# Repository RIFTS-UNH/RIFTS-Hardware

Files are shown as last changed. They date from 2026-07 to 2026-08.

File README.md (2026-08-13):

# RIFTS Hardware Documentation

Mechanical design archive and documentation for the **Radio Interferometer For Thunderstorm Studies (RIFTS)** project at the University of New Hampshire.

📖 **Live documentation site:** [rifts-unh.github.io/RIFTS-Hardware](https://rifts-unh.github.io/RIFTS-Hardware/)

This repository holds the source for that site. It covers mechanical enclosure design, additively manufactured components, CAD reference models, manufacturing files, environmental validation testing, and engineering lessons learned across the RIFTS hardware platforms — the RFSoC 4x2 portable field enclosure, the ZCU216 rack-mount enclosure, the OmniLOG antenna mount system, and supporting accessories.

For the full write-ups, navigation, and images, visit the site linked above rather than browsing this repo directly.

---

## Repository Contents

```
RIFTS-Hardware/
├── .github/
│   └── workflows/
│       └── deploy.yml   # builds and deploys the site to GitHub Pages on push to main
├── docs/                # mkdocs source (pages, images, assets for the documentation site)
├── mkdocs.yml            # site configuration
└── README.md
```

Large CAD assemblies and manufacturing archives are tracked with Git LFS. Clone with `git lfs install` set up beforehand, or run `git lfs pull` after cloning, to fetch them.

---

## Building the Site Locally

```bash
pip install mkdocs-material mkdocs-glightbox
mkdocs serve
```

Then open `http://127.0.0.1:8000` to preview locally. Pushes to `main` trigger `.github/workflows/deploy.yml`, which builds the site with `mkdocs build` and deploys it to GitHub Pages automatically.

---

## Acknowledgements

This hardware was developed as part of the **Radio Interferometer For Thunderstorm Studies (RIFTS)** project at the University of New Hampshire.

Additional hardware contributions and reference designs:

- **Frank Lind, MIT Haystack Observatory** — RF Interface Board reference design
- **AMD Xilinx** — ZCU216 RFSoC Development Platform, RFSoC 4x2 Development Platform
- **SparkFun Electronics** — ZED-F9T GNSS Timing Breakout, ESP32 WROOM Thing Plus

---

## Maintainer

Mechanical design and documentation: **Joshua D'Addario**

---

## FLASH-MEP

FLASH-MEP parts sheet  https://docs.google.com/spreadsheets/d/1aVYJW8B82nQ8EhuhUXIeyBJPT4pah5DBl2TXt3p7wDM/edit?gid=0#gid=0

Wed Aug 12 18:59:08 EDT 2026

## Revision History

| Revision | Date | Description |
| --- | --- | --- |
| Rev A | July 2026 | Initial RIFTS hardware documentation archive. |
| Rev B | Aug 2026  | Repository cleaned up to contain only mkdocs source and its GitHub Actions deploy workflow; README rewritten to point to the live site rather than duplicate it. |

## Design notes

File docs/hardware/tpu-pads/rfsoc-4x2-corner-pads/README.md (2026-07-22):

# RFSoC 4x2 TPU Corner Pad System

Installed Corner Pads

---

# Project Summary

| | |
|---|---|
| **Project** | RFSoC 4x2 TPU Corner Pad System |
| **Purpose** | Protective corner assemblies for portable enclosure handling and transportation |
| **Associated Platform** | RFSoC 4x2 Portable Field Enclosure |
| **Manufacturing Method** | FDM Additive Manufacturing |
| **Primary Material** | TPU |
| **Rigid Insert Material** | PLA Prototype / PETG Recommended |
| **Threaded Hardware** | M3 Brass Heat-Set Inserts |
| **Printer** | Bambu Lab A1 |
| **Status** | Complete |

---

# Overview

The RFSoC 4x2 TPU Corner Pad System was developed specifically for the portable RIFTS RFSoC 4x2 enclosure to improve durability during transportation, handling, and field deployment.

Unlike the laboratory-oriented ZCU216 enclosure, the RFSoC 4x2 platform was designed for repeated transportation and operation outside of a controlled laboratory environment.

The corner pad assemblies provide mechanical protection for the aluminum enclosure while improving stability when placed on uneven or irregular surfaces.

---

# Design Purpose

The corner pad assemblies were developed to:

- Protect enclosure corners during transportation and handling.
- Reduce impact forces transferred to the aluminum enclosure.
- Improve stability on uneven surfaces.
- Provide a high-friction interface between the enclosure and supporting surfaces.
- Improve long-term durability of the portable hardware platform.

---

# Assembly Design

Each enclosure corner uses a **unique corner pad assembly** designed to accommodate the specific geometry of that enclosure corner.

The complete system consists of four separate corner assemblies.

Each assembly contains:

- Four TPU body sections.
- Ten custom rigid insert components.
- Ten M3 brass heat-set threaded inserts.
- Mechanical fasteners for final assembly.

The rigid insert components are bonded into dedicated pockets within the TPU sections.

Because TPU is flexible and does not provide an ideal material for directly installing heat-set inserts, rigid printed inserts were incorporated to provide a more reliable threaded interface.

The heat-set inserts are installed into the rigid insert components, allowing the TPU sections to be mechanically fastened together into a complete three-dimensional corner pad assembly.

This modular construction allows damaged sections to be replaced individually rather than requiring replacement of an entire corner assembly.

---

# Material Selection

## TPU Corner Components

The protective corner sections were manufactured using Thermoplastic Polyurethane (TPU).

TPU was selected due to:

- High impact resistance.
- Flexibility under loading.
- Abrasion resistance.
- High surface friction.
- Ability to absorb mechanical shocks.

Compared with rigid thermoplastics, TPU provides improved energy absorption and reduces the likelihood of transmitting impact forces directly into the aluminum enclosure.

---

## Rigid Insert Components

The rigid insert components were originally manufactured using PLA to support rapid prototyping and design iteration.

For future manufacturing, **PETG is recommended** because it provides:

- Improved toughness.
- Increased impact resistance.
- Better elevated-temperature performance.
- Reduced brittleness during repeated assembly.

---

# Heat-Set Insert Installation

The M3 brass heat-set inserts are installed into the rigid printed insert components.

Recommended installation procedure:

1. Heat a soldering iron to approximately **230°C**.
2. Use a heat-set insert press attachment designed for soldering irons to maintain alignment during installation.
3. Insert the brass threaded insert into the prepared hole.
4. Ensure the **serrated face of the heat-set insert faces outward toward the opening of the hole**.
   - The serrated surface should face upward/outward.
   - It should not point deeper into the printed insert.
5. Apply heat and gently press the insert into position until fully seated.

A suitable heat-set insert press attachment can be purchased commercially.

Example:

https://www.amazon.com/Vertical-Machine-Heat-Insertion-Threaded-Components/dp/B0DHKPHKJZ

---

# Design Features

The completed corner pad assemblies provide:

- Full enclosure corner protection.
- Replaceable modular construction.
- Flexible impact absorption.
- Increased friction against supporting surfaces.
- Improved stability during transportation.
- Lightweight construction.

The modular design allows individual TPU sections or rigid inserts to be replaced without recreating the entire assembly.

---

# Gallery

## CAD Model

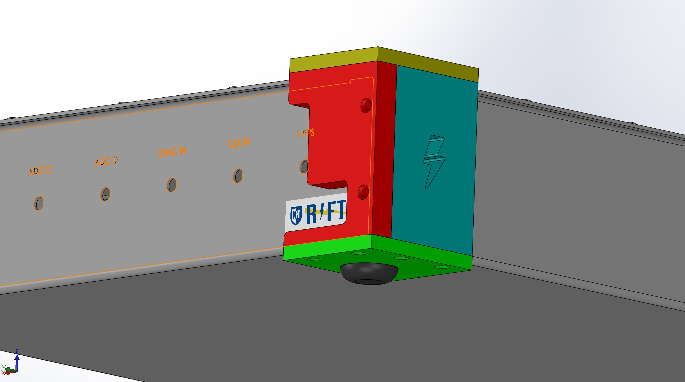
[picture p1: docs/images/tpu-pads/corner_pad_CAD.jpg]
Corner Pad CAD


Representative CAD model of a corner pad assembly.

---

## Installed Assembly

Installed Corner Pad

Completed corner pad assemblies installed on the RFSoC 4x2 enclosure.

---

# Manufacturing

The corner pad assemblies were manufactured using fused deposition modeling (FDM) additive manufacturing.

## Manufacturing Details

| Component | Material | Manufacturing Method |
|---|---|---|
| TPU corner sections | TPU | FDM 3D Printing |
| Rigid insert components | PLA Prototype / PETG Recommended | FDM 3D Printing |
| Threaded inserts | Brass M3 Heat-Set Inserts | Commercial Hardware |

Printer:

- Bambu Lab A1

Future manufacturing packages may include Bambu Studio (`.3mf`) files containing validated print profiles.

---

# File Organization

```text
rfsoc-4x2-corner-pads/

├── Common_Components/
│   └── Corner_Pad_Insert/
│       ├── CAD/
│       └── STL/
│
├── Corner_Pad_1/
│   ├── Assembly/
│   ├── CAD/
│   └── STL/
│
├── Corner_Pad_2/
│
├── Corner_Pad_3/
│
└── Corner_Pad_4/
```

---

# Downloads

The repository includes:

## Common Components

- Native SolidWorks CAD for rigid insert components.
- STL files for additive manufacturing.

## Corner Pad Assemblies

Each corner assembly includes:

- SolidWorks assembly files (`.SLDASM`).
- Native SolidWorks part files (`.SLDPRT`).
- STL files for additive manufacturing.

Future revisions may include:

- STEP exports.
- Exploded assembly drawings.
- Bambu Studio (`.3mf`) print files.

---

# Associated Hardware Platform

The corner pad system was developed exclusively for the RFSoC 4x2 portable enclosure.

These assemblies are not used on the ZCU216 enclosure platform.

---

# Revision History

| Revision | Date | Description |
|---|---|---|
| Rev A | July 2026 | Initial corner pad assembly documentation and archive release. |

---

# Credits

Mechanical design and documentation:

**Joshua D'Addario**

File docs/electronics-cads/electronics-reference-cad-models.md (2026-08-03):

# Electronics Reference CAD Models

## Overview

This section catalogs the mechanical CAD reference models of electronic hardware collected over the course of RIFTS project developments, used to support enclosure design, mechanical integration studies, connector placement verification, and internal packaging development.

These are **mechanical reference models only** — dimensional and geometric representations used for CAD integration work, not schematics, PCB layout, or electrical design files.

The collection includes both manufacturer-provided models and models created or derived in-house from available references, sourced from a mix of manufacturers, collaborators, and third parties.

---

## Models in This Collection

| Model | Designer / Manufacturer | Source | Simplified Version Available |
|---|---|---|:---:|
| AMD Xilinx RFSoC 4x2 Development Board | AMD | Provided directly by an AMD representative | Yes |
| AMD Xilinx ZCU216 Development Board | AMD | Purchased from a third-party CAD vendor | No |
| RF Interface Board | Frank Lind, MIT Haystack Observatory | Provided by the designer for RIFTS integration | Yes |
| SparkFun ZED-F9T GNSS Timing Breakout (Qwiic) | SparkFun Electronics | Converted from SparkFun's published Eagle files | No |
| SparkFun ESP32 WROOM Thing Plus (Micro B) | SparkFun Electronics | Converted from SparkFun's published Eagle files | No |
| Ethernet Cat5e Bulkhead Connector | Third-party | Sourced from GrabCAD | No |
| Type A Duct Fan | Sanyo Denki | Sourced from DigiKey | No |
| Type B Duct Fan | Sanyo Denki | Sourced from DigiKey | No |

!!! note "SparkFun models are board outline only"
    Both SparkFun models (ZED-F9T and ESP32 Thing Plus) represent the bare PCB geometry only — mounting holes, board outline, and connector locations — without populated components. Full component-level geometry could not be reliably converted from SparkFun's Eagle files. This was sufficient for the mechanical integration work these models were created for, but worth knowing in advance if you're requesting one for a different purpose.

---

## Requesting Files

!!! warning "Files not publicly distributed"
    These models are not available for direct download from this site. Ownership and redistribution rights vary by source — some are manufacturer-owned geometry, some are provided by outside collaborators, and some come from third-party repositories with unclear redistribution terms.

    If you need one of these files, **contact a RIFTS executive** to request it. They can determine whether a given model is appropriate to share on a case-by-case basis.

    <!-- TODO: add RIFTS executive contact name/email here -->

---

## How These Models Are Used

Reference models in this collection support:

- Enclosure and chassis design
- Mechanical integration studies across hardware platforms
- Connector and cable pathway placement
- Internal packaging and clearance verification
- General hardware visualization for documentation

Where appropriate, simplified versions of these models are used in place of full manufacturer geometry — removing unnecessary cosmetic and internal detail while preserving mechanically relevant features such as board envelope dimensions, mounting hole locations, and connector placement. This improves CAD performance during enclosure design work.

Simplified versions currently exist for the **AMD Xilinx RFSoC 4x2 Development Board** and the **RF Interface Board**. These simplified models retain only mechanically significant geometry — external dimensions, connector locations, and mounting interfaces — and are available as an alternative to the full-detail manufacturer models on request.

---

## Revision History

| Revision | Date | Description |
|---|---|---|
| Rev A | July 2026 | Initial electronics reference model catalog. |

---

## Credits

CAD collection and documentation: **Joshua D'Addario**

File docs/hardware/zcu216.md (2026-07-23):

# ZCU216 RF Shielded Enclosure

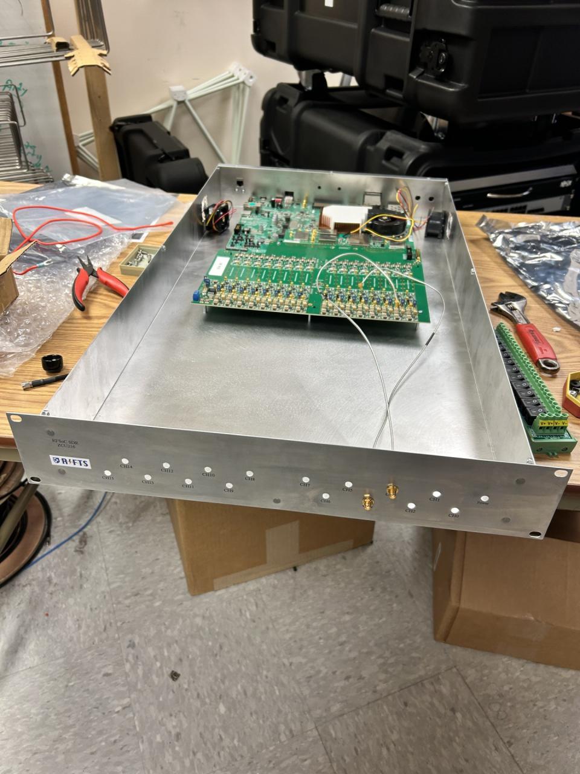
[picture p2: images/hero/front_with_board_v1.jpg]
ZCU216 Enclosure


## Project Summary

| | |
|---|---|
| **Project** | ZCU216 RF Shielded Enclosure |
| **Purpose** | EMI-shielded enclosure for laboratory integration of the AMD Xilinx ZCU216 RFSoC platform |
| **Platform** | AMD Xilinx ZCU216 RFSoC Development Board |
| **Application** | Radio Interferometer for Thunderstorm Studies (RIFTS) |
| **Manufacturer** | Protocase |
| **Material** | 5052 Aluminum |
| **Revision A Thickness** | 0.040 in (1.02 mm) |
| **Revision B Thickness** | 0.051 in (1.30 mm) |
| **Cooling** | Dual forced-air cooling (side-mounted intake and exhaust fans) |
| **Shielding Strategy** | Conductive aluminum enclosure with seam-welded construction, dense fastener spacing, and controlled aperture geometry |
| **Status** | Revision B Complete |
| **Related Hardware** | MIT Haystack RF Interface Board, RFSoC 4x2 Enclosure, Air Ducts |

---

## Overview

The ZCU216 RF Shielded Enclosure was the first major mechanical hardware platform developed for the University of New Hampshire's Radio Interferometer for Thunderstorm Studies (RIFTS) project.

The enclosure was designed to integrate the AMD Xilinx ZCU216 RFSoC development platform with the MIT Haystack RF Interface Board while providing mechanical protection, electromagnetic shielding, active cooling, and convenient laboratory operation within a standard 2U rack-mounted form factor.

Beyond simply housing electronics, this project established many of the mechanical design philosophies that would later influence the portable RFSoC 4x2 enclosure, including approaches to EMI mitigation, airflow management, manufacturability, and enclosure construction.

## Design Requirements

The enclosure was developed to satisfy several engineering requirements:

- Provide secure mechanical integration of the AMD Xilinx ZCU216 RFSoC platform.
- Integrate the MIT Haystack RF Interface Board within the same enclosure.
- Minimize electromagnetic emissions and susceptibility through conductive enclosure design.
- Support forced-air cooling for continuous laboratory operation.
- Package the system within a standard 2U rack-mounted form factor.
- Maintain accessibility to all required external interfaces.
- Allow repeatable assembly and servicing.

---

## Design Rationale

The enclosure was conceived as an RF engineering enclosure rather than simply a protective chassis. Several design decisions were driven specifically by electromagnetic compatibility (EMC) considerations.

### Conductive Construction

5052 aluminum was selected because it offers an excellent balance between electrical conductivity, manufacturability, corrosion resistance, structural performance, and cost.

Unlike painted steel enclosures or polymer housings, the conductive aluminum body contributes directly to electromagnetic shielding performance.

### Mechanical Rigidity

Revision A demonstrated that although 0.040-inch aluminum was adequate structurally, increasing wall thickness would substantially improve enclosure rigidity. Revision B therefore increased the enclosure thickness to 0.051-inch aluminum.

The resulting enclosure is noticeably more rigid during transportation, assembly, and servicing while also providing modest improvements in low-frequency shielding performance.

### Seam Welding

One of the most significant improvements introduced in Revision B was seam welding. Continuous welded seams eliminate narrow gaps that can behave as unintended slot antennas.

Reducing these discontinuities improves overall shielding effectiveness while simultaneously increasing enclosure rigidity. This change became one of the most influential design improvements carried forward into later RIFTS hardware.

### Cooling Strategy

Thermal management is provided using two internally mounted fans. Both the intake and exhaust fans are mounted directly to the enclosure side panels.

This arrangement produces a straightforward airflow path through the enclosure while simplifying manufacturing and maintenance. Unlike the later RFSoC 4x2 enclosure, neither fan is mounted directly to the RFSoC heatsink.

### EMI Shielding Philosophy

Rather than relying upon expensive conductive elastomer gaskets throughout the enclosure, the shielding strategy emphasized:

- Conductive aluminum construction
- Seam welding
- Controlled aperture geometry
- Dense fastener spacing around removable panels

This approach provided a practical balance between shielding performance and manufacturing cost.

---

## Key Engineering Improvements

| Revision | Major Improvements |
|---|---|
| **Rev A (August 2025)** | Initial enclosure design establishing overall architecture, board integration, cooling layout, and shielding strategy. |
| **Rev B (December 2025)** | Increased wall thickness, seam-welded construction, improved vent placement, relocated panel labels, and increased overall structural rigidity. |

---

## Mechanical Design

The enclosure consists of a welded aluminum chassis with a removable cover.

Internal features include mounting provisions for:

- AMD Xilinx ZCU216 RFSoC Development Board
- MIT Haystack RF Interface Board
- Forced-air cooling hardware
- Standardized Protocase PEM hardware

The removable cover provides convenient service access while maintaining shielding continuity through closely spaced fasteners.

---

## Gallery

### Complete Enclosure

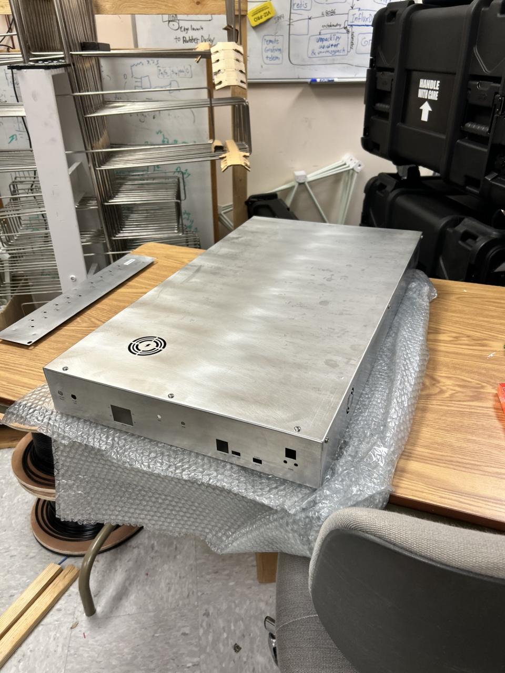
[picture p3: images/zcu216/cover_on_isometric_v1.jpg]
ZCU216 Isometric View

*Overall isometric view of the completed enclosure.*

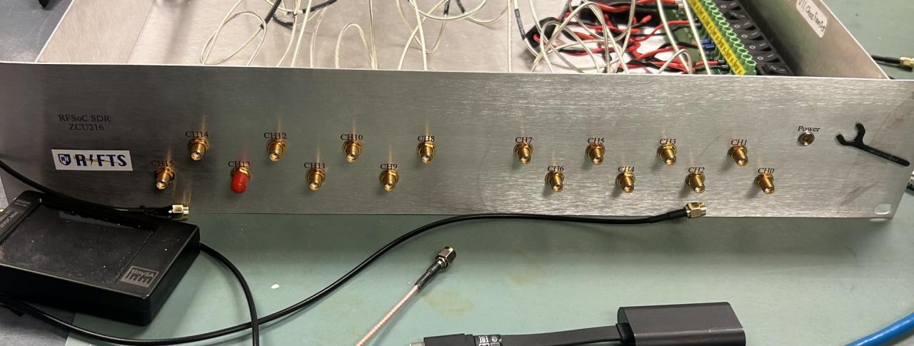
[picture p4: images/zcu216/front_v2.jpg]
Front View

*Front panel showing external interfaces and rack mounting features.*

### Internal Assembly

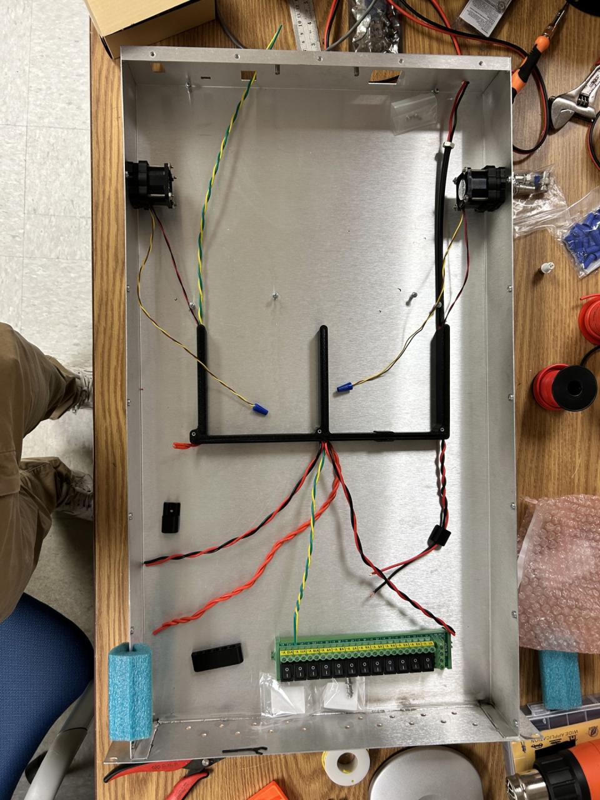
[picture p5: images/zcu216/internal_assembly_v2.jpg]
Internal Assembly

*Internal view showing the AMD Xilinx ZCU216 RFSoC platform, MIT Haystack RF Interface Board, cooling hardware, and enclosure layout.*

### Rear Panel

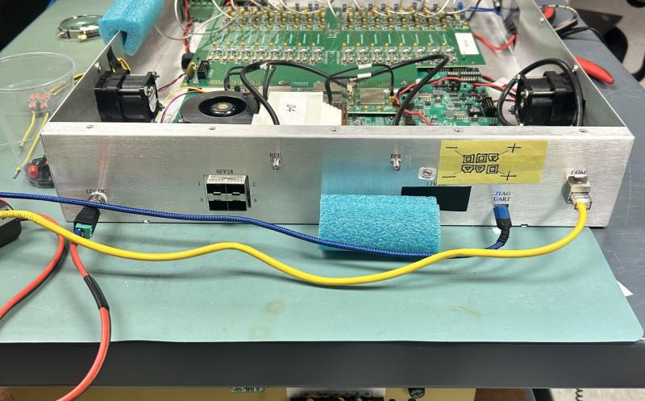
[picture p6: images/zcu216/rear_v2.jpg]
Rear Panel

*Rear panel detailing RF and electrical interfaces.*

---

## Directory Contents

The repository preserves both the final enclosure design and the reference models used throughout development.

### Board CAD

Reference CAD models used during enclosure development.

**AMD Xilinx ZCU216 Development Board**
`AMD_Xilinx_ZCU216_Board.SLDPRT` — manufacturer-supplied CAD model of the AMD Xilinx ZCU216 RFSoC development platform.

**MIT Haystack RF Interface Board**
`MIT_Haystack_RF_Interface_Board.SLDPRT` — high-fidelity CAD model of the RF Interface Board developed by Frank Lind at MIT Haystack Observatory.

**Simplified RF Interface Board**
`MIT_Haystack_RF_Interface_Board_Simplified.SLDPRT` — simplified reference model developed specifically for enclosure design. Only mechanically significant geometry was retained in order to improve SolidWorks performance while preserving:

- External dimensions
- Connector locations
- Mounting interfaces
- Overall board envelope

The simplified model is recommended for future enclosure development unless detailed internal geometry is required.

### Enclosure CAD

The completed enclosure model is provided in neutral CAD format.

Available formats:

- STEP

### Manufacturing Files

Manufacturing documentation includes the original fabrication package used for production by Protocase.

Available formats:

- Protocase PDA

These files preserve the exact enclosure geometry submitted for manufacturing and may be used for future revisions or reproduction.

---

## Manufacturing Notes

The enclosure was fabricated by Protocase using CNC sheet metal manufacturing techniques.

Standardized PEM hardware supplied by Protocase was incorporated throughout the design for board mounting and cover attachment. Although the enclosure was custom designed, the use of standardized manufacturing hardware simplified fabrication and ensured compatibility with Protocase manufacturing processes.

## CAD Model Notes

Several reference models are intentionally provided in both original and simplified forms.

The simplified models remove unnecessary cosmetic and internal features while preserving all mechanically significant geometry. Using simplified reference models substantially improves CAD performance, rebuild times, and assembly responsiveness without affecting enclosure design accuracy.

---

## Design Evolution

### Revision A — August 2025

Revision A represented the first complete enclosure manufactured for the RIFTS project. This revision established:

- Overall enclosure dimensions
- Internal board layout
- Cooling architecture
- RF interface board integration
- Initial EMI shielding strategy
- Rack-mount configuration

Revision A successfully demonstrated the overall enclosure concept while identifying several opportunities for refinement.

### Revision B — December 2025

Revision B incorporated the lessons learned during evaluation of the original enclosure. Major improvements included:

- Increased aluminum thickness from 0.040 in to 0.051 in
- Seam-welded chassis construction
- Improved vent alignment directly above the exhaust fan
- Relocation of engraved panel labels above connector cutouts
- Increased overall enclosure rigidity

These improvements resulted in a noticeably more robust enclosure while simultaneously improving shielding performance and manufacturability. Revision B represents the final iteration of the ZCU216 enclosure.

---

## Historical Context

The ZCU216 enclosure served as the foundation for subsequent RIFTS hardware development.

Many design concepts introduced during this project — including shielding strategies, cooling philosophy, enclosure construction techniques, and manufacturing practices — directly influenced the development of the later RFSoC 4x2 field enclosure.

The evolution from Revision A to Revision B also demonstrated the value of iterative hardware development, where practical experience informed meaningful engineering improvements in later designs.

## Lessons Learned

Development of the ZCU216 enclosure produced several important engineering insights:

- Increasing enclosure wall thickness significantly improved structural rigidity without substantially increasing manufacturing complexity.
- Seam welding improved both enclosure stiffness and electromagnetic shielding by eliminating narrow conductive discontinuities that could behave as slot antennas.
- Small improvements in panel layout, such as centering ventilation openings and relocating engraved labels, noticeably improved overall usability and appearance.
- Simplified CAD models dramatically reduced SolidWorks assembly complexity while maintaining mechanical accuracy.
- Designing for manufacturability early in the CAD process reduced later manufacturing revisions.

---

## Engineering Notes

### PEM Hardware Selection

Protocase PEM hardware follows standardized dimensions. When selecting threaded standoffs, designers should note that the published dimensions correspond to the hardware **before installation**.

Because part of each PEM becomes embedded within the sheet metal during installation, the installed height will be shorter than the catalog dimension. Future enclosure designs should account for this reduction when selecting standoff lengths.

### Cooling Layout

Both cooling fans are mounted directly to the enclosure side panels. This arrangement simplifies assembly while providing effective airflow through the enclosure.

Future modifications should preserve a clear intake-to-exhaust airflow path.

### Shielding Philosophy

The enclosure intentionally relies upon conductive construction, welded seams, controlled aperture geometry, and dense fastener spacing rather than extensive use of conductive elastomer gaskets.

While conductive gaskets can further improve shielding performance, they also introduce additional manufacturing cost and assembly complexity.

### Serviceability

The removable cover provides straightforward access to all major internal components. Future enclosure modifications should preserve this accessibility whenever possible.

---

## Future Work

Although Revision B represents a mature enclosure design, several opportunities remain for future refinement:

- Evaluation of conductive EMI gasket materials for removable panels.
- Investigation of thicker aluminum construction comparable to the later RFSoC 4x2 enclosure.
- Additional quantitative shielding effectiveness measurements across a broader frequency range.
- Improved cable management features within the enclosure.
- Integration of future RF hardware platforms using the established enclosure architecture.

## Retrospective

The overall enclosure architecture has proven successful and would remain largely unchanged.

If beginning the project again, I would prioritize seam-welded construction and thicker aluminum from the initial revision rather than introducing those improvements after the first production enclosure.

I would also investigate the selective use of conductive EMI gaskets at removable panel interfaces to further improve shielding effectiveness, particularly at higher frequencies where dense fastener spacing alone becomes less effective.

Aside from these refinements, Revision B represents a well-balanced compromise between shielding performance, manufacturability, serviceability, and cost.

---

## Related Documentation

- [RFSoC 4x2 Enclosure](../rfsoc-4x2/README.md)
- [Air Ducts](../../Accessories/Air_Ducts/README.md)
- [RF Pathway](../../Accessories/RF_Pathway/README.md)

---

## Revision History

| Revision | Date | Description |
|---|---|---|
| Rev A | August 2025 | Initial enclosure manufactured and delivered by Protocase using 0.040 in 5052 aluminum. |
| Rev B | December 2025 | Increased wall thickness to 0.051 in, seam-welded construction, improved vent placement, updated panel labeling, and increased structural rigidity. |

---

## Credits

**Mechanical Design, CAD, and Documentation**
Joshua D'Addario — University of New Hampshire, Engineering Physics

**RF Hardware**
AMD Xilinx — ZCU216 RFSoC Development Platform
Frank Lind, MIT Haystack Observatory — RF Interface Board

**Manufacturing**
Protocase — custom precision sheet metal fabrication.

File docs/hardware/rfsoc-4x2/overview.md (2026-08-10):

# RFSoC 4x2 Portable Field Enclosure

## Project Summary

| | |
|---|---|
| **Project** | RFSoC 4x2 Portable Field Enclosure |
| **Purpose** | Portable EMI-shielded enclosure for field deployment of the AMD Xilinx RFSoC 4x2 platform |
| **Platform** | AMD Xilinx RFSoC 4x2 Development Board |
| **Application** | Radio Interferometer for Thunderstorm Studies (RIFTS) |
| **Manufacturer** | Protocase |
| **Material** | 5052 Aluminum |
| **Material Thickness** | 0.064 in (1.63 mm) |
| **Cooling** | Dual forced-air cooling with heatsink-mounted exhaust fan |
| **Shielding Strategy** | Conductive aluminum enclosure with seam-welded construction, dense fastener spacing, and controlled aperture geometry |
| **Status** | Final Design Complete |
| **Related Hardware** | RF Pathway, Air Ducts, TPU Corner Pads |

---

## HD Renders

<div class="render-scroll" markdown>

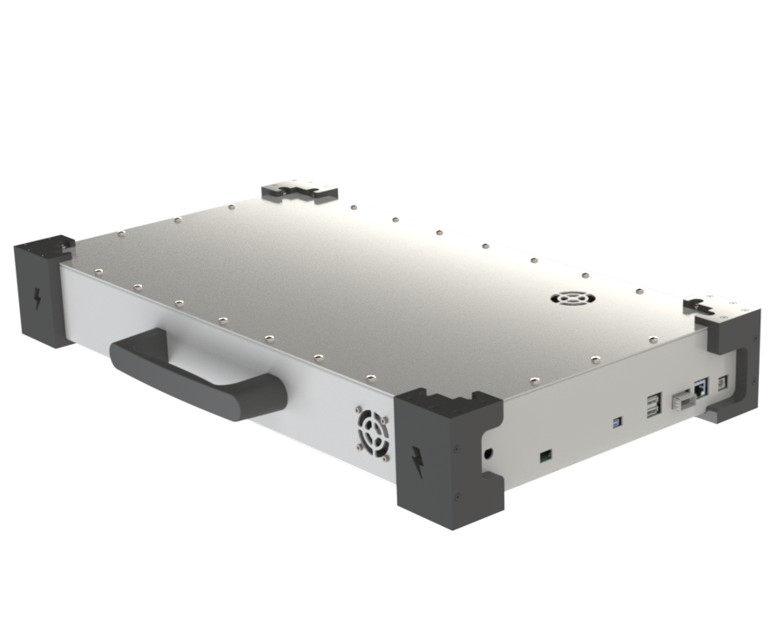
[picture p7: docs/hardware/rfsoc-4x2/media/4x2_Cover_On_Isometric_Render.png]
RFSoC 4x2 Enclosure Render 1


<!-- ![RFSoC 4x2 Enclosure Render 2](media/4x2_Hero_Render.png){: data-gallery="rfsoc-4x2-renders" } -->

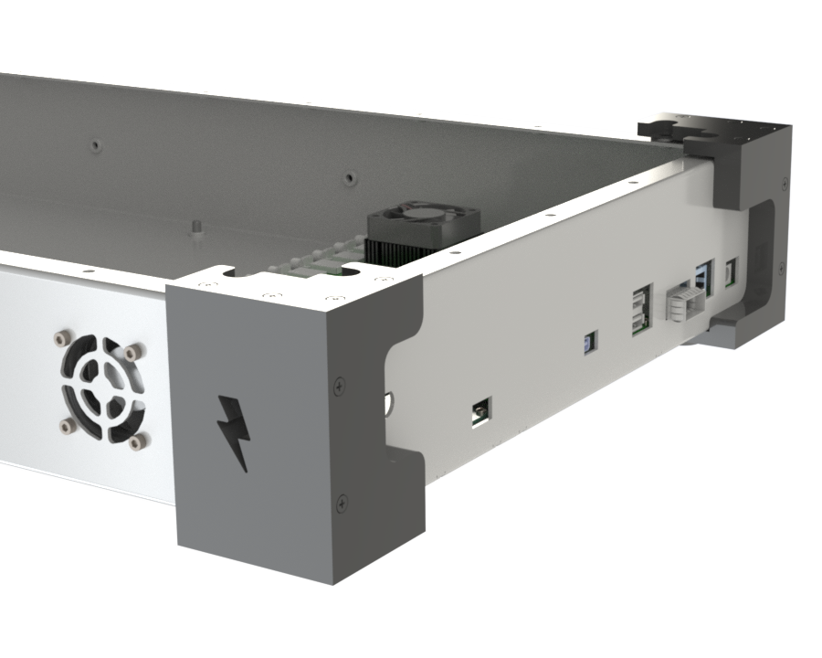
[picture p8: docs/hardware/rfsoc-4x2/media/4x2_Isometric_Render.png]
RFSoC 4x2 Enclosure Render 3


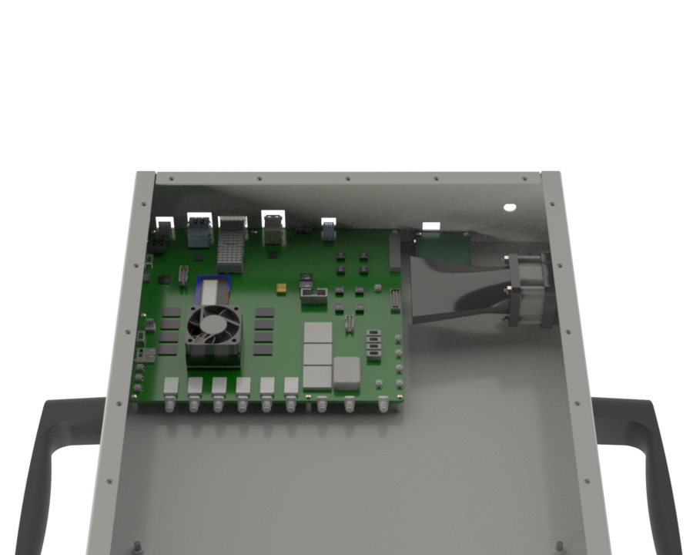
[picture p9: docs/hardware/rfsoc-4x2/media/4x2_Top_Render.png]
RFSoC 4x2 Enclosure Render 4


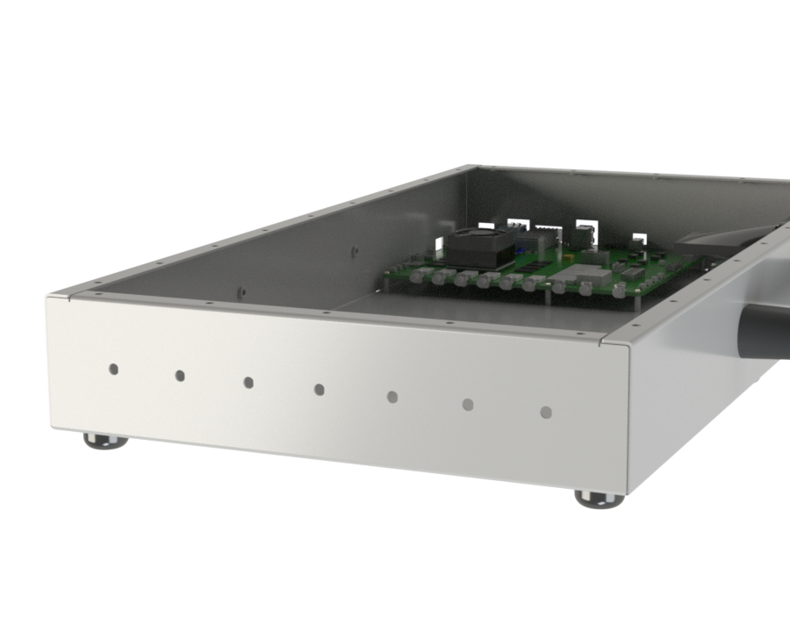
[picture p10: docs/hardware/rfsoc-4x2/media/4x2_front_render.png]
RFSoC 4x2 Enclosure Render 4


</div>

<!-- Scroll strip — add more renders by appending additional image lines above, same pattern. -->

---

## Overview

The RFSoC 4x2 Portable Field Enclosure was developed as the second major enclosure platform for the University of New Hampshire's Radio Interferometer for Thunderstorm Studies (RIFTS) project.

Unlike the earlier ZCU216 enclosure, which was intended primarily for laboratory integration within a standard 2U rack-mounted form factor, the RFSoC 4x2 enclosure was designed specifically for mobile field deployments. It was engineered to provide mechanical protection, electromagnetic shielding, thermal management, and portability while supporting transportation by vehicle and operation in outdoor research environments.

Although the enclosure itself is not waterproof, it was designed to integrate with the project's weather-resistant antenna systems and neighboring RF electronics during field campaigns.

The RFSoC 4x2 enclosure also represents the culmination of several lessons learned during development of the earlier ZCU216 enclosure, particularly with respect to structural rigidity, EMI shielding, and enclosure construction techniques.

---

## Design Requirements

The enclosure was designed to satisfy the following engineering requirements:

- Provide secure mechanical integration of the AMD Xilinx RFSoC 4x2 development platform.
- Protect sensitive RF electronics during transportation and field deployment.
- Minimize electromagnetic emissions and susceptibility through conductive enclosure design.
- Provide active cooling for continuous operation.
- Maintain access to all required RFSoC interfaces.
- Support rapid deployment and transportation.
- Accommodate the project's custom RF pathway assemblies.
- Maintain a serviceable mechanical design.

## Design Rationale

### Portable Field Deployment

Unlike the ZCU216 enclosure, portability became a primary design objective. Integrated carrying handles and rubber feet allow the enclosure to be transported by hand, placed securely within vehicles, and operated on uneven terrain or standard laboratory work surfaces.

### Structural Improvements

Experience gained from the ZCU216 enclosure directly influenced the mechanical construction of the RFSoC 4x2 enclosure. It utilizes **0.064-inch 5052 aluminum**, the thickest enclosure material used on the RIFTS project. The increased thickness provides noticeably greater rigidity during transportation and handling while also contributing to improved low-frequency shielding performance. As with the later revision of the ZCU216 enclosure, seam-welded construction further improves both structural integrity and electromagnetic shielding effectiveness.

### RFSoC 4x2 Mounting Strategy

The initial enclosure concept followed the mounting philosophy established by the ZCU216 enclosure, positioning the RFSoC development board flush against the rear enclosure wall. During integration it became apparent that this arrangement would obstruct access to the RFSoC 4x2's JTAG/UART interface, located along the side of the development board.

To preserve accessibility, the board was relocated into a rear corner of the enclosure, allowing connector cutouts to be incorporated into both the rear panel and one side panel while maintaining a compact footprint. Although this significantly improved connector accessibility, it also made installation of the development board onto the threaded standoffs more challenging due to the reduced working space around the board.

### Thermal Management

The RFSoC 4x2 enclosure incorporates an active cooling system consisting of two fans. The intake fan is mounted directly to one side panel. Unlike previous designs, the exhaust fan is mounted directly to the heatsink supplied with the RFSoC 4x2 development board — heated air is drawn directly from the heatsink and exhausted through a dedicated vent in the enclosure cover.

Additional airflow management is provided through custom FDM-printed air ducts developed specifically for the enclosure, improving airflow direction and cooling efficiency while remaining easily manufacturable using desktop additive manufacturing.

### RF Pathway Integration

Rather than utilizing the MIT Haystack RF Interface Board employed by the ZCU216 platform, the RFSoC 4x2 enclosure incorporates four analog RF pathway assemblies. Because complete vendor CAD models were unavailable, an engineering reference model of the RF pathway was reverse engineered from available measurements and visual references. Although not intended to represent manufacturing geometry, the model accurately captures the overall size, connector locations, and mechanical envelope required for enclosure integration.

---

## Mechanical Design

The enclosure consists of a seam-welded aluminum chassis with a removable fastened cover. Major mechanical features include:

- Integrated carrying handles
- Six rubber isolation feet
- RFSoC 4x2 mounting provisions
- Side-mounted intake fan
- Heatsink-mounted exhaust fan
- Dedicated ventilation openings
- Standardized Protocase PEM hardware

The removable cover provides full access to the enclosure interior while maintaining shielding continuity through closely spaced perimeter fasteners.

---

## Manufacturing

The enclosure was manufactured by [Protocase](https://www.protocase.com/) using CNC sheet metal fabrication from 0.064-inch 5052 aluminum. Compared to the earlier ZCU216 enclosure, the increased material thickness provided substantially greater rigidity for transportation and field handling while maintaining good manufacturability.

The enclosure utilizes standardized Protocase PEM hardware for board mounting and removable cover attachment.

!!! note "Protocase Contact"
    UNH customer representative: [jhurd@protocase.com](mailto:jhurd@protocase.com)

### Manufacturing Compliance Issue Report

Only one enclosure design was produced. Following delivery of the initial manufactured enclosure, it was discovered that several PEM fasteners intended to secure the removable cover had been installed incorrectly during manufacturing, preventing the cover from being removed using the intended screw-fastened assembly.

The enclosure design itself required no modification. A replacement enclosure was manufactured using the original design with corrected PEM installation.

---

<!-- Reusable block — Protocase CAD Template Generator. Paste this section as-is into any other enclosure page on the site. -->

## Design Tool: Protocase CAD Template Generator

Protocase offers a free [CAD Template Generator](https://www.protocase.com/products/services/design/template-generator/) that streamlines the early stages of enclosure design. Given a set of basic specifications, the tool generates a blank, manufacturable CAD template (DXF or STEP) for the selected enclosure, bracket, or panel style, which can then be opened directly in standard CAD software and customized with cutouts, fasteners, brackets, partitions, hardware, and graphics before being submitted back to Protocase for quoting.

This tool proved invaluable throughout the design of this enclosure, as well as other enclosures developed for the RIFTS project, by providing a manufacturable starting geometry and reducing the design time otherwise spent building enclosure envelopes from scratch.

**How it works:**

1. Fill out the short form on the Template Generator page to request access.
2. Select from over 50 available enclosure, bracket, and panel styles and provide the relevant specifications.
3. Receive a blank CAD template (DXF/STEP) by email.
4. Open the template in your preferred CAD software and customize it with cutouts, fasteners, brackets, partitions, hardware, and graphics.
5. Submit the finalized design back to Protocase for a manufacturing quote.

<!-- End reusable block -->

---

## Design Evolution

Unlike the ZCU216 enclosure, the RFSoC 4x2 enclosure did not undergo multiple design revisions after manufacturing began. Instead, the design was revised several times during the pre-fabrication design phase, incorporating lessons learned from previous RIFTS hardware projects before the initial fabrication. The only additional unit produced was the replacement enclosure described above under Manufacturing.

---

## Engineering Notes

### Cover Removal

The removable cover is secured using twenty-eight perimeter fasteners spaced approximately 2.5 inches apart. This dense spacing was intentionally selected to reduce the effective length of conductive discontinuities around the removable cover, improving electromagnetic shielding without requiring conductive EMI gaskets. Although effective from an EMC perspective, removing the cover requires significant assembly time.

Future enclosure designs could improve serviceability by replacing circular fastener holes along the long sides of the cover with slotted features, allowing the corresponding fasteners to remain partially installed while the cover slides free after loosening — reducing disassembly time without compromising shielding performance.

### RFSoC Installation

Positioning the RFSoC 4x2 in the rear corner of the enclosure successfully preserved access to both rear and side interfaces. However, this location leaves limited clearance when installing the development board onto the threaded standoffs. Future revisions should investigate alternative mounting strategies that preserve connector accessibility while simplifying installation.

### PEM Hardware Selection

Protocase PEM hardware follows standardized dimensions. When selecting threaded standoffs, designers should note that the published dimensions correspond to the hardware **before installation** — part of each PEM becomes embedded within the sheet metal during installation, so the installed height will be shorter than the catalog dimension. This was accounted for in the standoff selection for the RFSoC 4x2 enclosure, so no correction is needed if additional units of this enclosure design are manufactured in the future. Future *new* enclosure designs should account for this reduction when selecting standoff lengths.

Standardized PEM standoffs were selected to mount the two PCBs housed within the enclosure — the RFSoC 4x2 development board and the SparkFun GNSS timing breakout board — accounting for board thickness, required standoff height, and each board's mounting hole pattern:

| PCB | Standoff Part Number |
|-----|---|
| AMD Xilinx RFSoC 4x2 | TSOS-256-500 |
| SparkFun ZED-F9T GNSS Timing Breakout (Qwiic) | BSO4-M3-12 |

The full Protocase standoff catalog is available at [protocase.com/products/components/standoff](https://www.protocase.com/products/components/standoff/) for reference when selecting standoffs for future revisions.

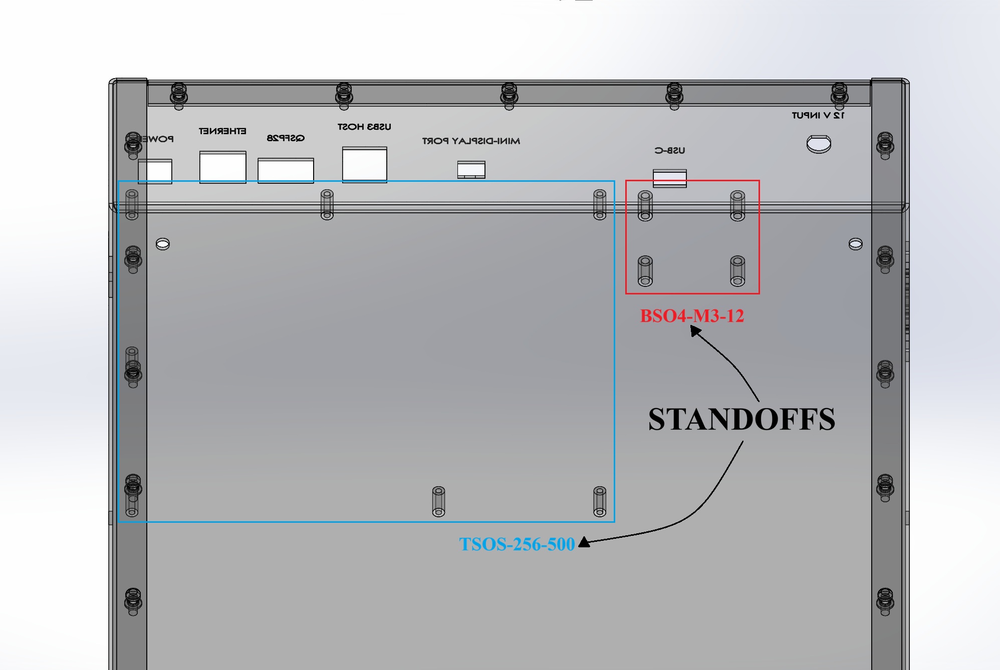
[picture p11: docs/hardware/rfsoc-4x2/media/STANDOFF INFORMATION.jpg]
Standoff Placement Diagram


Diagram illustrating standoff placement and type for each PCB within the enclosure.
{: .figure-caption }

#### Board Installation Video

<div class="video-wrap" markdown="1">

<video controls>
  <source src="../media/4x2_board_installation_tutorial.mp4" type="video/mp4">
  Your browser does not support the video tag.
</video>

SolidWorks walkthrough showing installation of the RFSoC 4x2 development board and the GNSS timing breakout board onto their respective standoffs within the enclosure.
{: .video-caption }

</div>

<!-- TODO: confirm final video filename/path once uploaded -->

---

## Lessons Learned & Retrospective

The RFSoC 4x2 enclosure represents the culmination of approximately eighteen months of mechanical design work on the RIFTS project. While the finished enclosure successfully met its design objectives, development surfaced several recurring engineering themes:

- Designing for easy access is just as important as mechanical packaging — dense fastener spacing improved shielding continuity but significantly increased assembly and service time (see Engineering Notes above).
- Preserving connector accessibility by corner-mounting the RFSoC 4x2 came at the cost of installation difficulty, underscoring the need to weigh accessibility against assemblability early in the design process.
- Early consideration of assembly procedures can eliminate unnecessary maintenance effort later in a project's lifecycle.
- Experience gained from the ZCU216 enclosure translated directly into a more rigid, better-shielded portable design.

Perhaps the greatest lesson was the value of iterative engineering — incorporating lessons from prior RIFTS hardware *before* fabrication, rather than through multiple post-production revisions, ultimately produced a more robust design. It reinforced that successful engineering comes from continual refinement rather than a perfect first attempt.

---

## Future Work

Although the enclosure successfully met its design objectives, several opportunities remain for future refinement:

- Slotted removable cover for faster servicing.
- Improved RFSoC mounting strategy to simplify installation.
- Evaluation of conductive EMI gaskets for removable panel interfaces.
- Additional quantitative shielding effectiveness measurements.
- Continued refinement of airflow management accessories.
- Integration of future RF hardware platforms using the established enclosure architecture.

---

## Related Hardware

Several accessories were developed specifically for the RFSoC 4x2 enclosure and are documented elsewhere on this site. Together, these components complete the portable field enclosure assembly:

- [RF Pathway](../rfsoc-4x2-rf-pathway.md)
- [Cooling Air Ducts](../ventilation/air-ducts.md) *(includes the fan CAD reference)*
- [TPU Corner Pads](../tpu-pads/corner-pads-overview.md)

---

## Revision History

| Revision | Date | Description |
|---|---|---|
| Rev A | 06/12/2026 | Initial enclosure manufactured and delivered by Protocase. |
| Rev A (replacement) | 07/13/2026 | Replacement enclosure produced to correct PEM installation compliance issue. |

---

## Credits

**Mechanical Design, CAD, and Documentation**
Joshua D'Addario — University of New Hampshire, Engineering Physics

**Project Support and Technical Guidance**
Dr. Ningyu Liu — University of New Hampshire, Principal Investigator, RIFTS
Stephen Horn — University of New Hampshire, Senior Member, RIFTS Research Team

**Hardware Platform**
AMD Xilinx — RFSoC 4x2 Development Platform
SparkFun Electronics — Auxiliary Platforms

**Manufacturing**
[Protocase](https://www.protocase.com/) — custom precision sheet metal fabrication

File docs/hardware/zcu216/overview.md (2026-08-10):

# ZCU216 RF Shielded Enclosure

## Project Summary

| | |
|---|---|
| **Project** | ZCU216 RF Shielded Enclosure |
| **Purpose** | EMI-shielded enclosure for laboratory integration of the AMD Xilinx ZCU216 RFSoC platform |
| **Platform** | AMD Xilinx ZCU216 RFSoC Development Board |
| **Application** | Radio Interferometer for Thunderstorm Studies (RIFTS) |
| **Manufacturer** | Protocase |
| **Material** | 5052 Aluminum |
| **Revision A Thickness** | 0.040 in (1.02 mm) |
| **Revision B Thickness** | 0.051 in (1.30 mm) |
| **Cooling** | Triple forced-air cooling (side-mounted intake and exhaust fans, plus a heatsink-mounted fan venting through the cover) |
| **Shielding Strategy** | Conductive aluminum enclosure with seam-welded construction, dense fastener spacing, and controlled aperture geometry |
| **Status** | Revision B Complete |
| **Related Hardware** | MIT Haystack RF Interface Board, Air Ducts, RFIB Support |

---

## HD Renders

<div class="render-scroll" markdown>

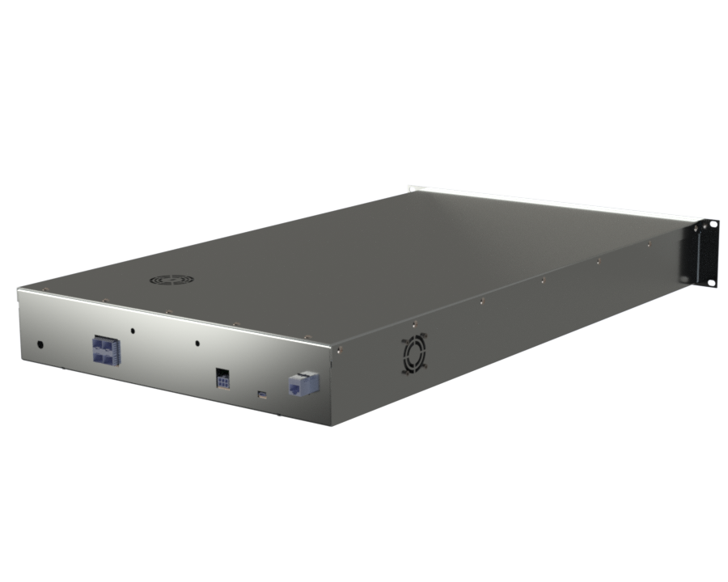
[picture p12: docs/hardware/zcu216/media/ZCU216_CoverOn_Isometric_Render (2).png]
ZCU216 Enclosure Render 1


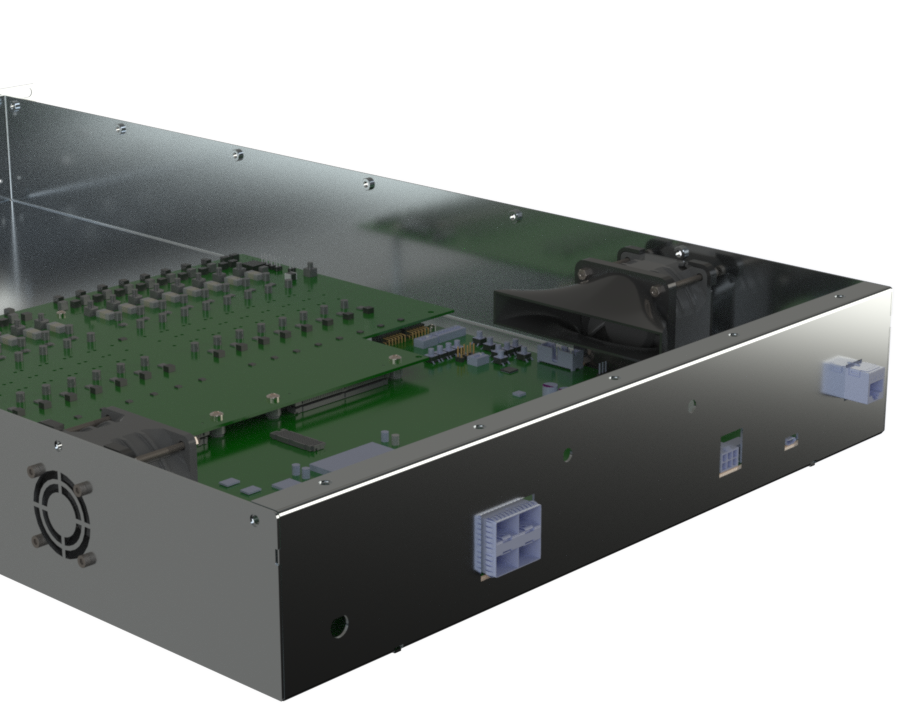
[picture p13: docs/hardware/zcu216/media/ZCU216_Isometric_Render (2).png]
ZCU216 Enclosure Render 2


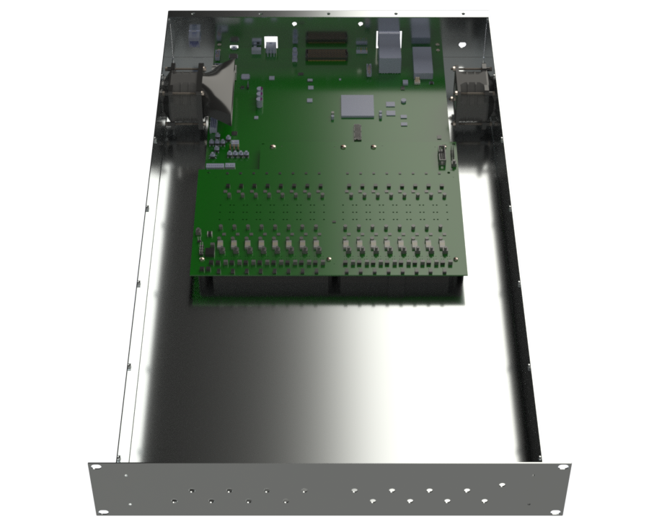
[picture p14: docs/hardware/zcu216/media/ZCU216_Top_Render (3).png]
ZCU216 Enclosure Render 3


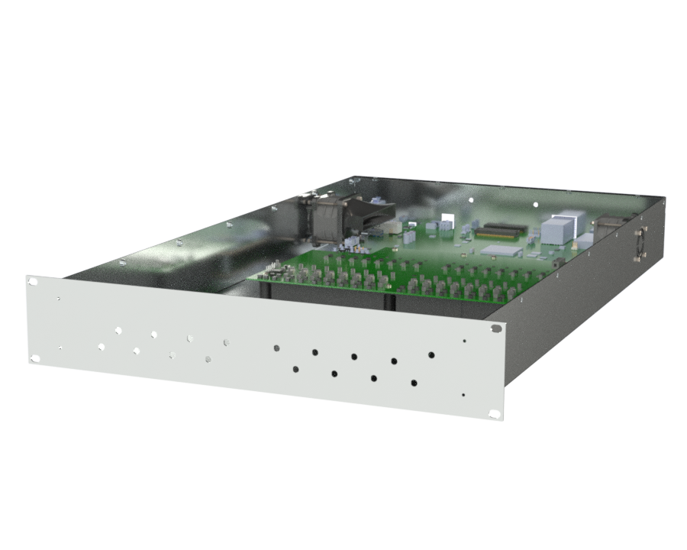
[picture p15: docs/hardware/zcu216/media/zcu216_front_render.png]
ZCU216 Enclosure Render 3


<!-- ![ZCU216 Enclosure Render 4](../../images/zcu216/renders/ZCU216_Render_04.jpg){: data-gallery="zcu216-renders" } -->

</div>

<!-- Scroll strip — add more renders by appending additional image lines above, same pattern. -->

!!! note
    Where visible, these renders depict the enclosure fitted with the **Type B (Short) air duct system** — chosen for these renders simply because it looks cooler than the Type A (Short) variant. Both duct types are functionally interchangeable; see [Cooling Air Ducts](../ventilation/air-ducts.md) for details on both.

---

## Overview

The ZCU216 RF Shielded Enclosure was the first major enclosure platform developed for the University of New Hampshire's Radio Interferometer for Thunderstorm Studies (RIFTS) project.

The enclosure was designed to integrate the AMD Xilinx ZCU216 RFSoC development platform with the MIT Haystack RF Interface Board while providing mechanical protection, electromagnetic shielding, active cooling, and convenient laboratory operation within a standard 2U rack-mounted form factor.

Beyond simply housing electronics, this project established many of the mechanical design philosophies that would later influence the portable RFSoC 4x2 enclosure, including approaches to EMI mitigation, airflow management, manufacturability, and enclosure construction.

---

## Design Requirements

The enclosure was developed to satisfy several engineering requirements:

- Provide secure mechanical integration of the AMD Xilinx ZCU216 RFSoC platform.
- Integrate the MIT Haystack RF Interface Board within the same enclosure.
- Minimize electromagnetic emissions and susceptibility through conductive enclosure design.
- Support forced-air cooling for continuous laboratory operation.
- Package the system within a standard 2U rack-mounted form factor.
- Maintain accessibility to all required external interfaces.
- Allow repeatable assembly and servicing.

## Design Rationale

The enclosure was conceived as an RF engineering enclosure rather than simply a protective chassis. Several design decisions were driven specifically by electromagnetic compatibility (EMC) considerations.

### Conductive Construction

5052 aluminum was selected because it offers an excellent balance between electrical conductivity, manufacturability, corrosion resistance, structural performance, and cost. Unlike painted steel enclosures or polymer housings, the conductive aluminum body contributes directly to electromagnetic shielding performance.

### Mechanical Rigidity

Revision A demonstrated that although 0.040-inch aluminum was adequate structurally, increasing wall thickness would substantially improve enclosure rigidity. Revision B therefore increased the enclosure thickness to 0.051-inch aluminum.

The resulting enclosure is noticeably more rigid during transportation, assembly, and servicing while also providing modest improvements in low-frequency shielding performance.

### Seam Welding

One of the most significant improvements introduced in Revision B was seam welding. Continuous welded seams eliminate narrow gaps that can behave as unintended slot antennas.

Reducing these discontinuities improves overall shielding effectiveness while simultaneously increasing enclosure rigidity. This change became one of the most influential design improvements carried forward into later RIFTS hardware.

### Cooling Strategy

Thermal management is provided using two side-panel mounted fans in addition to a dedicated heatsink-mounted fan. The intake and exhaust fans are mounted directly to the enclosure side panels, establishing the primary airflow path through the enclosure. A third fan is mounted directly to the ZCU216's heatsink; heated air is drawn from the heatsink and pushed upward through a dedicated vent in the enclosure cover.

This arrangement produces effective, multi-path airflow through the enclosure while remaining straightforward to manufacture and service. This heatsink-mounted exhaust approach was later carried forward and expanded upon in the RFSoC 4x2 enclosure.

### EMI Shielding Philosophy

Rather than relying upon expensive conductive elastomer gaskets throughout the enclosure, the shielding strategy emphasized:

- Conductive aluminum construction
- Seam welding
- Controlled aperture geometry
- Dense fastener spacing around removable panels

This approach provided a practical balance between shielding performance and manufacturing cost.

---

## Mechanical Design

The enclosure consists of a welded aluminum chassis with a removable cover. Internal features include mounting provisions for:

- AMD Xilinx ZCU216 RFSoC Development Board
- MIT Haystack RF Interface Board
- Forced-air cooling hardware
- Standardized Protocase PEM hardware

The removable cover provides convenient service access while maintaining shielding continuity through closely spaced fasteners.

---

## Manufacturing

The enclosure was fabricated by Protocase using CNC sheet metal manufacturing techniques.

Standardized PEM hardware supplied by Protocase was incorporated throughout the design for board mounting and cover attachment. Although the enclosure was custom designed, the use of standardized manufacturing hardware simplified fabrication and ensured compatibility with Protocase manufacturing processes.

!!! note "Protocase Contact"
    UNH customer representative: [jhurd@protocase.com](mailto:jhurd@protocase.com)

---

<!-- Reusable block — Protocase CAD Template Generator. Paste this section as-is into any other enclosure page on the site. -->

## Design Tool: Protocase CAD Template Generator

Protocase offers a free [CAD Template Generator](https://www.protocase.com/products/services/design/template-generator/) that streamlines the early stages of enclosure design. Given a set of basic specifications, the tool generates a blank, manufacturable CAD template (DXF or STEP) for the selected enclosure, bracket, or panel style, which can then be opened directly in standard CAD software and customized with cutouts, fasteners, brackets, partitions, hardware, and graphics before being submitted back to Protocase for quoting.

This tool proved invaluable throughout the design of this enclosure, as well as other enclosures developed for the RIFTS project, by providing a manufacturable starting geometry and reducing the design time otherwise spent building enclosure envelopes from scratch.

**How it works:**

1. Fill out the short form on the Template Generator page to request access.
2. Select from over 50 available enclosure, bracket, and panel styles and provide the relevant specifications.
3. Receive a blank CAD template (DXF/STEP) by email.
4. Open the template in your preferred CAD software and customize it with cutouts, fasteners, brackets, partitions, hardware, and graphics.
5. Submit the finalized design back to Protocase for a manufacturing quote.

<!-- End reusable block -->

---

## Design Evolution

### Revision A — August 2025

Revision A represented the first complete enclosure manufactured for the RIFTS project. This revision established:

- Overall enclosure dimensions
- Internal board layout
- Cooling architecture
- RF interface board integration
- Initial EMI shielding strategy
- Rack-mount configuration

Revision A successfully demonstrated the overall enclosure concept while identifying several opportunities for refinement.

### Revision B — December 2025

Revision B incorporated the lessons learned during evaluation of the original enclosure. Major improvements included:

- Increased aluminum thickness from 0.040 in to 0.051 in
- Seam-welded chassis construction
- Improved vent alignment directly above the heatsink-mounted fan
- Relocation of engraved panel labels above connector cutouts
- Increased overall enclosure rigidity

These improvements resulted in a noticeably more robust enclosure while simultaneously improving shielding performance and manufacturability. Revision B represents the final iteration of the ZCU216 enclosure.

---

## Engineering Notes

### PEM Hardware Selection

Protocase PEM hardware follows standardized dimensions. When selecting threaded standoffs, designers should note that the published dimensions correspond to the hardware **before installation** — part of each PEM becomes embedded within the sheet metal during installation, so the installed height will be shorter than the catalog dimension. This was accounted for in the standoff selection for the ZCU216 enclosure, so no correction is needed if additional units of this enclosure design are manufactured in the future. Future *new* enclosure designs should account for this reduction when selecting standoff lengths.

Standardized PEM standoffs were selected to mount the two PCBs housed within the enclosure — the AMD Xilinx ZCU216 development board and the MIT Haystack RF Interface Board — accounting for board thickness, required standoff height, and each board's mounting hole pattern:

| PCB | Standoff Part Number |
|-----|---|
| AMD Xilinx ZCU216 | BSO-440-1871 |
| RF Interface Board | BSO-440-32Z1 |

The full Protocase standoff catalog is available at [protocase.com/products/components/standoff](https://www.protocase.com/products/components/standoff/) for reference when selecting standoffs for future revisions.

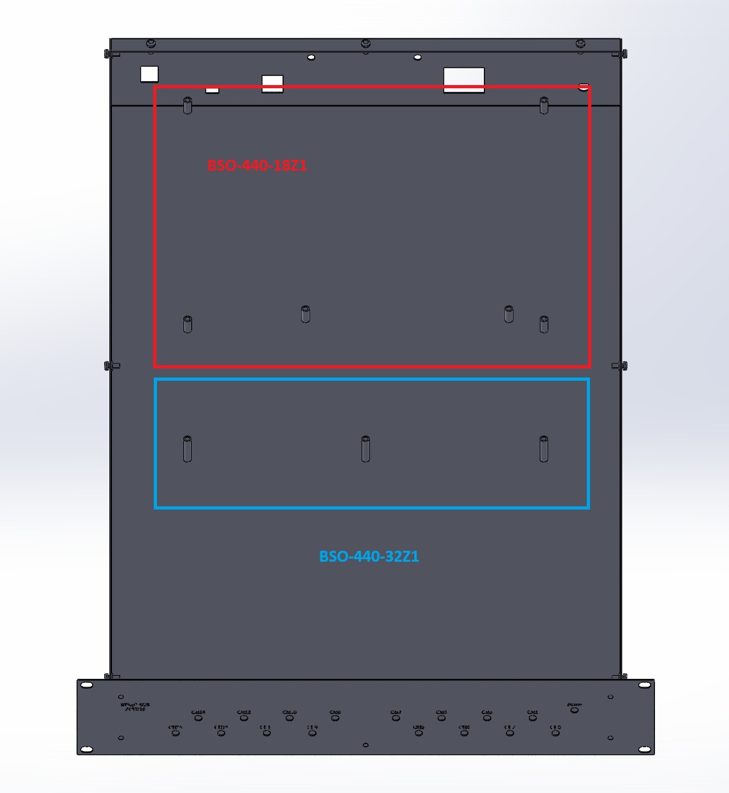
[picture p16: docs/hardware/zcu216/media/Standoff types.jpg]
Standoff Types


Standoff types used for the ZCU216 and RF Interface Board mounting.
{: .figure-caption }

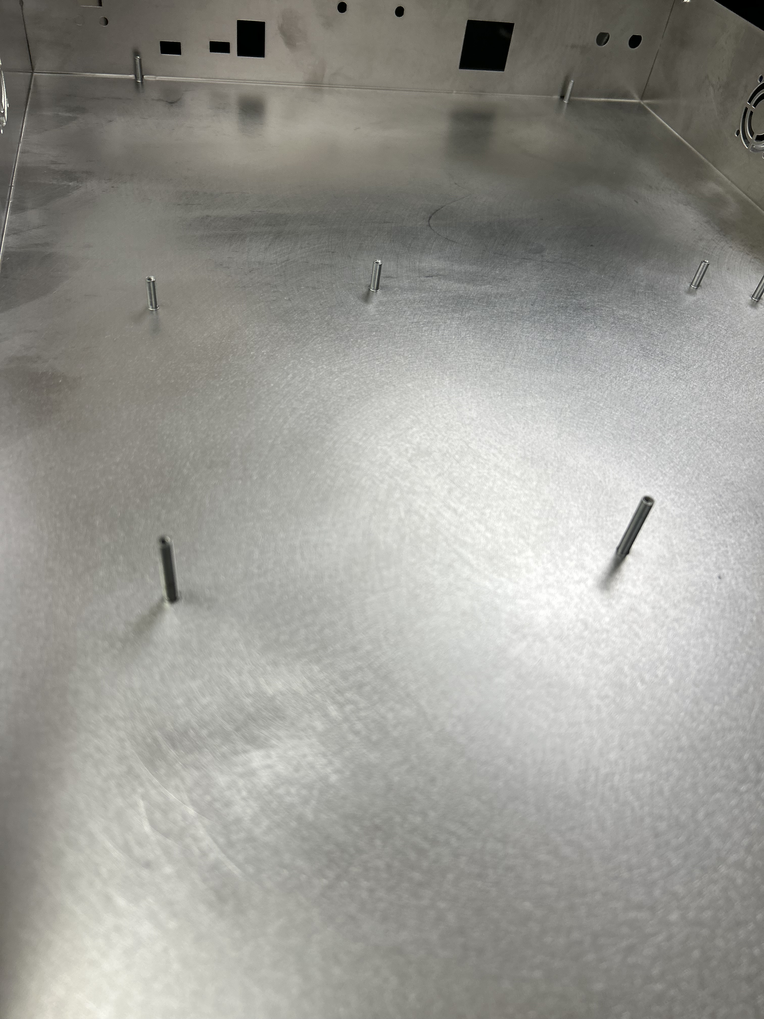
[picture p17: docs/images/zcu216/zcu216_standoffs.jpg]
Standoff Placement


Standoffs within the ZCU216 enclosure.
{: .figure-caption }

#### Board Installation Video

<div class="video-wrap" markdown="1">

<video controls>
  <source src="../media/ZCU216_Board_Installation_Tutorial.mp4" type="video/mp4">
  Your browser does not support the video tag.
</video>

SolidWorks walkthrough showing installation of the AMD Xilinx ZCU216 development board, [RF Interface Board (RFIB) Support](../RFIB-support/rfib-support.md), and the MIT Haystack RF Interface Board onto their respective standoffs within the enclosure.
{: .video-caption }

</div>

<!-- TODO: confirm final video filename/path once uploaded -->

### Cooling Layout

Two fans are mounted directly to the enclosure side panels, providing the primary intake and exhaust path. A third fan is mounted directly to the ZCU216 heatsink and exhausts upward through a dedicated vent in the enclosure cover. This arrangement simplifies assembly while providing effective, multi-path airflow through the enclosure. Future modifications should preserve a clear airflow path for all three fans.

### Shielding Philosophy

See EMI Shielding Philosophy under Design Rationale above — the enclosure intentionally relies on conductive construction, welded seams, and fastener spacing rather than gaskets, trading some shielding performance for reduced manufacturing cost and assembly complexity.

### Serviceability

The removable cover provides straightforward access to all major internal components. Future enclosure modifications should preserve this accessibility whenever possible.

---

## Lessons Learned & Retrospective

Development of the ZCU216 enclosure produced several important engineering insights:

- Increasing enclosure wall thickness significantly improved structural rigidity without substantially increasing manufacturing complexity.
- Seam welding improved both enclosure stiffness and electromagnetic shielding by eliminating narrow conductive discontinuities that could behave as slot antennas.
- Small improvements in panel layout, such as centering ventilation openings and relocating engraved labels, noticeably improved overall usability and appearance.
- Simplified CAD models dramatically reduced SolidWorks assembly complexity while maintaining mechanical accuracy.
- Designing for manufacturability early in the CAD process reduced later manufacturing revisions.

The overall enclosure architecture has proven successful and would remain largely unchanged. If beginning the project again, seam-welded construction and thicker aluminum would be prioritized from the initial revision rather than introduced after the first production enclosure. Selective use of conductive EMI gaskets at removable panel interfaces would also be worth investigating, particularly at higher frequencies where dense fastener spacing alone becomes less effective.

Aside from these refinements, Revision B represents a well-balanced compromise between shielding performance, manufacturability, serviceability, and cost.

---

## Future Work

Although Revision B represents a mature enclosure design, several opportunities remain for future refinement:

- Evaluation of conductive EMI gasket materials for removable panels.
- Investigation of thicker aluminum construction comparable to the later RFSoC 4x2 enclosure.
- Additional quantitative shielding effectiveness measurements across a broader frequency range.
- Improved cable management features within the enclosure.
- Integration of future RF hardware platforms using the established enclosure architecture.

---

## Related Hardware

- MIT Haystack RF Interface Board (see [Electronics Reference CAD Models](../../electronics-cads/electronics-reference-cad-models.md))
- [Cooling Air Ducts](../ventilation/air-ducts.md)
- [RF Interface Board (RFIB) Support](../RFIB-support/rfib-support.md)

---

## Revision History

| Revision | Date | Description |
|---|---|---|
| Rev A | August 2025 | Initial enclosure manufactured and delivered by Protocase using 0.040 in 5052 aluminum. |
| Rev B | December 2025 | Increased wall thickness to 0.051 in, seam-welded construction, improved vent placement, updated panel labeling, and increased structural rigidity. |

---

## Credits

**Mechanical Design, CAD, and Documentation**
Joshua D'Addario — University of New Hampshire, Engineering Physics

**Project Support and Technical Guidance**
Dr. Ningyu Liu — University of New Hampshire, Principal Investigator, RIFTS
Stephen Horn — University of New Hampshire, Senior Member, RIFTS Research Team

**RF Hardware and Reference Designs**
AMD Xilinx — ZCU216 RFSoC Development Platform, RFSoC 4x2 Development Platform
Dr. Frank Lind, MIT Haystack Observatory — RF Interface Board

**Manufacturing**
[Protocase](https://www.protocase.com/) — custom precision sheet metal fabrication

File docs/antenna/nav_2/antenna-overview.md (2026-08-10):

# OmniLOG PRO 1030 N Antenna Mount System

## Project Summary

| | |
|---|---|
| **Project** | OmniLOG PRO 1030 N Antenna Mount System |
| **Purpose** | Weather-resistant dielectric mounting system for field deployment of the Aaronia OmniLOG PRO 1030 N antenna |
| **Platform** | Aaronia OmniLOG PRO 1030 N |
| **Application** | Radio Interferometer for Thunderstorm Studies (RIFTS) |
| **Manufacturing Method** | FDM Additive Manufacturing |
| **Primary Material** | ASA-CF |
| **Prototype Materials** | PLA, TPU, ABS |
| **Environmental Sealing** | 50 mm ID × 3.5 mm CS O-ring, silicone grease, M16L waterproof cable gland, 12 wall loops on printed components to resist moisture migration through layer lines |
| **Validation Testing** | Water immersion testing consistent with IPX7-style conditions (not formally certified) |
| **Electromagnetic Design** | Dielectric construction to minimize RF scattering and reduce susceptibility to multipath effects |
| **Status** | Final Design Complete |
| **Related Hardware** | Water Immersion Test Fixture |

---

## HD Renders  

<div class="render-scroll" markdown>

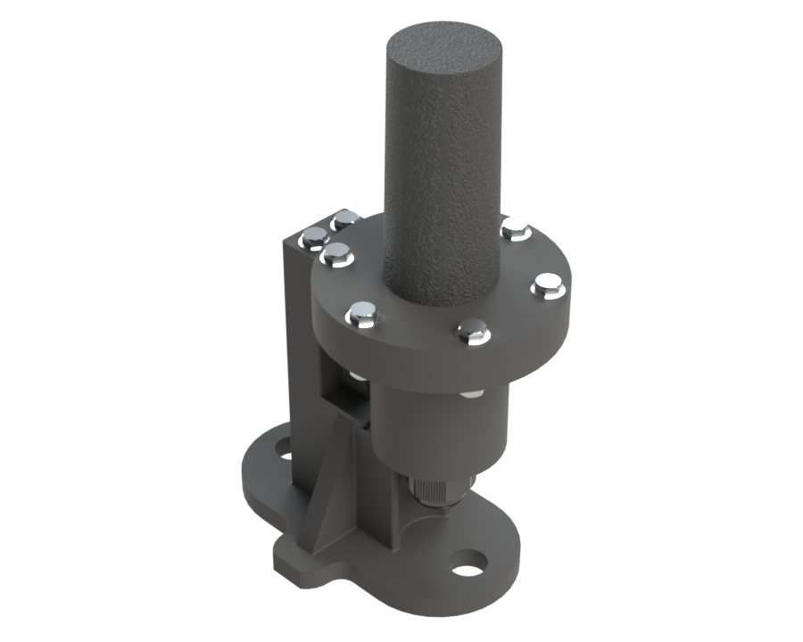
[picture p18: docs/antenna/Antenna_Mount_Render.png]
Antenna Mount Render 1


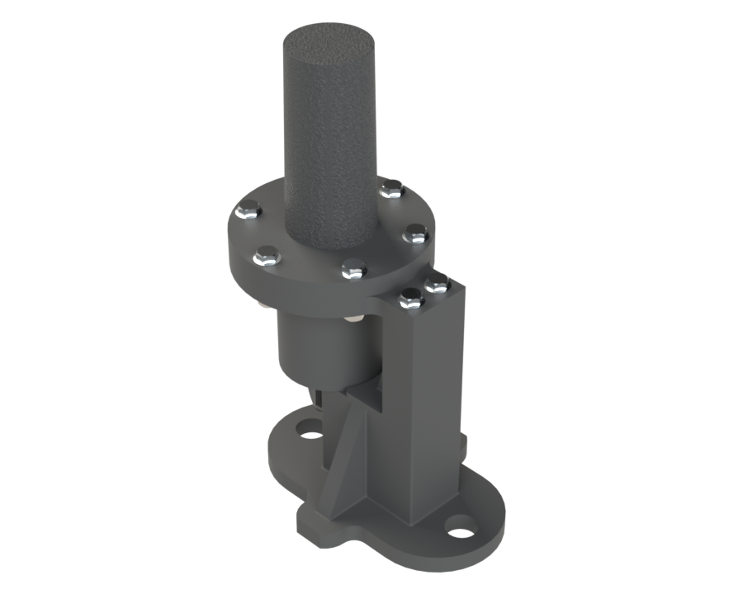
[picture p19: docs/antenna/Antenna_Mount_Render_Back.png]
Antenna Mount Render 2


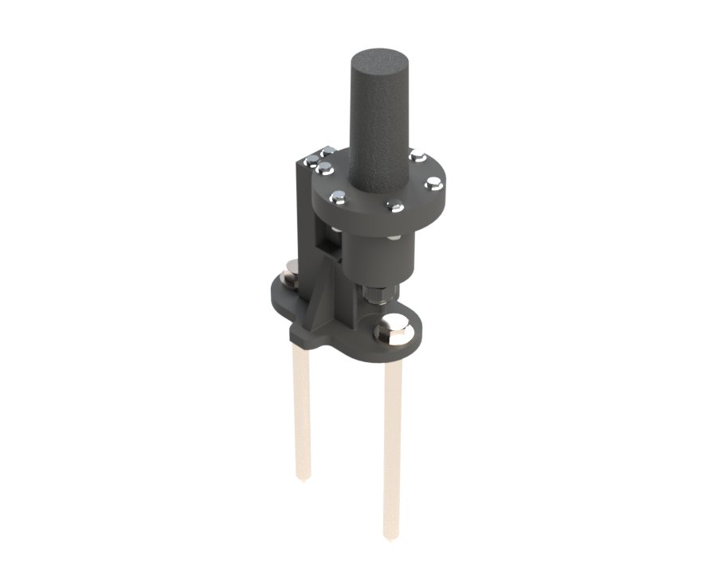
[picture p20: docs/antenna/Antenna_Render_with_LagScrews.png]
Antenna Mount Render 3


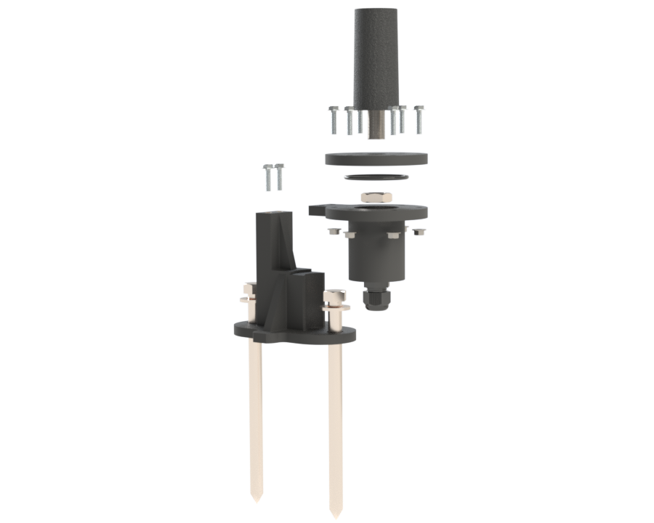
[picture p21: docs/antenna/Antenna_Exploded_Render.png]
Antenna Mount Render 4


</div>

<!-- Scroll strip — add more renders by appending additional image lines above, same pattern. -->

---

## Overview

The OmniLOG PRO 1030 N Antenna Mount System was developed as a rugged, field-deployable mounting solution for the RIFTS lightning observation platform.

The mount was designed to support outdoor deployment of the **Aaronia AG OmniLOG PRO 1030 N** antenna while addressing several challenges associated with field measurements, including environmental protection, mechanical stability, and electromagnetic interference from nearby structures.

Unlike conventional metallic mounting hardware, this design utilizes dielectric materials to reduce unwanted electromagnetic reflections and minimize potential multipath effects near the antenna.

---

## Design Requirements

The antenna mount was designed to satisfy the following requirements:

- Provide a stable ground-mounted platform for field deployment
- Protect antenna connections and electronics from environmental exposure
- Minimize electromagnetic interference from the mounting structure
- Support repeated deployment and transportation
- Allow rapid field installation and removal
- Maintain a serviceable and modular mechanical design

---

## Electromagnetic Design Considerations

A key design consideration was reducing unwanted electromagnetic interactions between the antenna mounting structure and incoming RF signals.

Traditional metallic mounting structures can introduce additional reflections and scattering near an antenna, potentially affecting measurements through multipath effects. To mitigate this concern, the mount was designed using dielectric materials rather than metal structural components, minimizing the likelihood of the mounting hardware acting as an unintended RF scatterer.

The mounting system was also designed to position the antenna approximately 1.5 feet lower than the original mounting configuration. By reducing the antenna height above the ground, the design sought to decrease the path length difference between direct and ground-reflected signals, helping to mitigate multipath effects arising from ground reflections during field measurements.

The resulting design provides a mechanically robust mounting solution while reducing potential sources of RF scattering and multipath that could influence measurement quality.

---

## Mechanical Design

The antenna mount consists of three primary printed components:

1. **Top Lid**
2. **Cylindrical Housing**
3. **Ground Mounting Mast**

### Top Lid

The top lid provides the mechanical interface for the OmniLOG PRO 1030 N antenna. Features include:

- Central antenna stem pass-through
- Threaded antenna retention interface
- Integrated O-ring sealing groove
- Mechanical interface to the cylindrical housing

The antenna is secured through the lid using the threaded antenna stem and retaining hardware.

### Cylindrical Housing

The cylindrical housing contains the antenna electronic stem and provides environmental protection, sealed against the top lid and fitted with a waterproof cable entry point. Full sealing hardware and specifications are detailed under Environmental Sealing below.

### Ground Mounting Mast

The mounting mast provides the interface between the antenna enclosure and the ground anchoring system. Features include:

- Two mounting holes for ground stakes
- Two M5 heat-set inserts for attaching the cylindrical housing
- Integrated seat that supports the base of the cylindrical housing, requiring no additional fasteners

The final field deployment configuration uses 8-inch ground stakes driven into the surrounding terrain.

---

## Environmental Sealing

The enclosure was designed for outdoor operation and underwent water immersion testing. Environmental sealing is achieved through two primary interfaces, supplemented by a print setting applied across all printed enclosure components: each is printed with 12 wall loops, increasing wall density and reducing the likelihood of moisture migrating inward through layer lines.

### Lid Seal

The interface between the top lid and cylindrical housing uses:

- One 50 mm × 3.5 mm (ID × CS) O-ring
- Molykote 111 silicone grease, applied lightly to the O-ring
- Stainless steel M5 hardware

The O-ring provides the primary environmental barrier between the lid and cylindrical housing. Only a light coating of silicone grease is required — its purpose is to improve seating and sealing performance, not to fill the O-ring groove, so excess grease should be avoided.

Early prototypes evaluated custom TPU-printed O-rings which did not provide the desired sealing performance, leading to the adoption of a commercially manufactured nitrile rubber O-ring for validation testing. The nitrile O-ring was selected for the prototype and testing phases due to its availability and reliable performance.

For long-term outdoor deployment, silicone remains the preferred O-ring material for this application, given its superior low-temperature flexibility. However, a silicone O-ring matching the required dimensions (50 mm ID × 3.5 mm CS) could not be readily sourced. A **fluoroelastomer (FKM)** O-ring of the same size, rated to −15 °F, was identified as a practical substitute — it should perform adequately for outdoor use through New England winters, though silicone would still be the superior choice if a matching size becomes available. See the **Manufacturing Details** page for the specific sourced part and commercial link.

### Cable Entry Seal

Cable routing is provided through one M16L waterproof cable gland, which prevents water and debris ingress through the lower enclosure interface while allowing antenna cabling to exit the sealed chamber.

The internal locking nut of the cable gland must be tightened from inside the cylindrical housing interface — a long socket wrench or sufficiently narrow access tool may be required due to the confined geometry.

For validation results, see Water Immersion Testing below.

---

## Design Evolution

The top lid and cylindrical housing were the last components to reach their final geometry, and once finalized, went largely unchanged for the remainder of development aside from one earlier iteration. The ground mounting structure took a very different path: many wholly different design concepts were made and evaluated for the ground mount before settling on the current mast geometry. Independent of geometry, materials were evaluated throughout development for performance and field suitability.

| Version | Material | Purpose |
|---|---|---|
| Prototype | PLA | Initial geometry verification and rapid iteration |
| Field Evaluation | ABS + UV-resistant coating | Outdoor testing and deployment evaluation |
| Final Production Design | ASA-CF | Planned long-term field deployment |

All versions were manufactured using a Bambu Lab A1 FDM printer, using Bambu Lab filament materials throughout development.

Two ABS prototypes are currently deployed in the field for continued evaluation. The final ASA-CF production units have not yet been manufactured.

---

## Manufacturing

The antenna mount was manufactured using fused deposition modeling (FDM) additive manufacturing. The validated manufacturing package includes native CAD files, STL files, Bambu Studio project files (`.3mf`), and documented slicer settings — including the 12-wall-loop setting used to help resist moisture ingress (see Environmental Sealing above).

For detailed printer parameters, orientation rationale, structural settings, and the full bill of materials, see the **Manufacturing Details** page.

---

## Assembly Procedure

### Installation Video

<div class="video-wrap" markdown="1">

<video controls>
  <source src="../../Antenna_Mount_Installation_Tutorial.mp4" type="video/mp4">
  Your browser does not support the video tag.
</video>

SolidWorks assembly walkthrough covering the full sequence below — O-ring installation through final housing attachment. Refer to the written steps for reference while assembling.
{: .video-caption }

</div>

<!-- TODO: confirm final video filename/path once uploaded -->

!!! warning "Cable routing not shown in video"
    Step 4 (Route Antenna Cable) was omitted from the video — the cable routing looked visually awkward in the SolidWorks animation, so it was left out. **Don't skip this step during actual assembly**: the cable must be routed through the cable gland, into the cylindrical housing, and up to the base of the antenna stem before sealing the top lid to the housing. See the written steps below for the full sequence.

### Written Steps

The recommended assembly sequence is:

**1. Install O-ring** — Lightly coat the 50 mm × 3.5 mm O-ring with silicone grease and install it into the sealing groove on the top lid. Only a minimal amount of grease is required.

**2. Install Antenna** — Secure the antenna to the top lid using the retaining hardware supplied with the antenna. The antenna should be fully secured before continuing assembly.

**3. Install Cable Gland** — Install the M16L cable gland into the cylindrical housing. Using a long socket wrench or narrow access tool, tighten the internal locking nut from inside the housing.

**4. Route Antenna Cable** — Route the cable from the neighboring electronics enclosure through the cable gland and into the cylindrical housing. The cable should exit through the top of the housing and connect to the base of the antenna stem.

**5. Seal Top Lid to Housing** — Join the top lid and cylindrical housing using the six M5 fasteners, tightening the nuts in a star pattern to ensure even O-ring compression and consistent sealing pressure.

**6. Install Ground Mast** — Mount the ground mast at the desired deployment location using the ground stakes before attaching the antenna housing assembly, so the mast can be secured without handling the completed antenna assembly.

**7. Attach Housing Assembly** — Attach the completed top lid and cylindrical housing assembly to the mast using the two additional M5 mounting screws installed into the mast's heat-set inserts.

The antenna mount is now successfully deployed.

---

## Water Immersion Testing

A custom water immersion test fixture was designed and fabricated to evaluate enclosure sealing. The fixture consisted of:

- 5-inch diameter PVC pipe, 1-meter length
- PVC end cap
- Custom 3D printed support structure

The antenna mount successfully demonstrated water resistance consistent with an IPX7-style immersion test. The PVC test fixture itself exhibits minor leakage after several hours; however, this did not prevent evaluation of the antenna mount sealing performance.

Formal dust ingress testing was not performed; therefore, no dust protection rating is claimed.

<div class="download-card compact" markdown>
<span class="card-icon">:fontawesome-solid-cube:</span>

**Test Fixture Support**

<p class="card-actions-row" markdown>
[:fontawesome-solid-cube: STL](../../media/antenna-mount/RIFTS_WaterImmersion_FixtureSupport.STL){: .card-action :download}
[:fontawesome-solid-print: 3MF](../../media/antenna-mount/RIFTS_WaterImmersion_FixtureSupport_PrintPackage.3mf){: .card-action :download}
</p>

</div>

---

## Revision History

| Revision | Date | Description |
|---|---|---|
| Rev A | July 2026 | Initial antenna mount documentation and archive release. |

---

## Credits

**Mechanical Design, CAD, and Documentation**
Joshua D'Addario — University of New Hampshire, Engineering Physics

**Project Support and Technical Guidance**
Dr. Ningyu Liu — University of New Hampshire, Principal Investigator, RIFTS
Stephen Horn — University of New Hampshire, Senior Member, RIFTS Research Team

**Hardware**
Aaronia — OmniLOG PRO 1030 N

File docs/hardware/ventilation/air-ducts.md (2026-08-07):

# Cooling Air Ducts & Fans

## Project Summary

| | |
|---|---|
| **Project** | Cooling Air Ducts & Fans |
| **Purpose** | Shared airflow management ducting for enclosure-mounted fans across RIFTS hardware platforms |
| **Platform** | ZCU216 RF Shielded Enclosure, RFSoC 4x2 Portable Field Enclosure |
| **Application** | Radio Interferometer for Thunderstorm Studies (RIFTS) |
| **Manufacturing Method** | FDM Additive Manufacturing |
| **Prototype Material** | PLA |
| **Recommended Material** | PETG or ABS |
| **Duct Variants** | Type A, Type B — each with Standard and Short length options |
| **Status** | Final Design Complete |
| **Related Hardware** | ZCU216 RF Shielded Enclosure, RFSoC 4x2 Portable Field Enclosure |

---

Shared thermal management components developed for use with RIFTS enclosure platforms.

The air duct assemblies improve airflow management by directing fan-generated airflow toward intended cooling regions within the enclosure.

Applicable platforms:

- ZCU216 Rack-Mounted Enclosure
- RFSoC 4x2 Portable Field Enclosure

---

## Design Overview

Two duct variants were developed — **Type A** and **Type B** — each consisting of two printed components that work together around a single fan:

- **Fan Mount** — attaches the fan itself to the enclosure panel.
- **Airflow Duct** — attaches to the opposite side of the fan and channels the exhaust into a more uniform, streamlined flow.

Both duct types share this same two-part mounting approach; the difference between Type A and Type B lies in their geometry, sized for the specific fan and airflow requirements of their target enclosure.

Each duct type also has a **Short** variant of the airflow duct, sized to fit within the ZCU216 enclosure — the original (Standard) airflow duct fits the RFSoC 4x2 enclosure. The Fan Mount component is shared between both variants; only the airflow duct length differs.

!!! note "Fan reference models included"
    The actual manufacturer fan CAD isn't included in these downloads due to IP restrictions. Instead, each SolidWorks and Neutral Bundle below includes a simplified **reference model** for that duct type's fan — a block matching the real fan's major footprint and four-hole mounting pattern at true dimensions, without any proprietary internal detail. It's intended for enclosure packaging, clearance checks, and mounting verification only, not as a substitute for the manufacturer's actual model.

!!! note "Short variant installation"
    No separate installation video was recorded for the Short variants — installation is identical to the Standard variants shown below, only the duct length differs.

### Installation Video — Type A

<div class="video-wrap" markdown="1">

<video controls>
  <source src="../media/Type_A/Type_A_Installation_Tutorial.mp4" type="video/mp4">
  Your browser does not support the video tag.
</video>

SolidWorks assembly walkthrough showing the Type A fan + duct assembly mounting to the enclosure wall.
{: .video-caption }

</div>

<!-- TODO: replace with actual video filename once exported/uploaded to docs/hardware/ventilation/media/Type_A/ -->

### Installation Video — Type B

<div class="video-wrap" markdown="1">

<video controls>
  <source src="../media/Type_B/Type_B_Installation_Tutorial.mp4" type="video/mp4">
  Your browser does not support the video tag.
</video>

SolidWorks assembly walkthrough showing the Type B fan + duct assembly mounting to the enclosure wall.
{: .video-caption }

</div>

<!-- TODO: replace with actual video filename once exported/uploaded to docs/hardware/ventilation/media/Type_B/ -->

---

## Fans

Type A and Type B ducts are sized around two different Sanyo Denki San Ace fans, differing in frame size, airflow, and static pressure to suit their target enclosure.

| | Type A Fan | Type B Fan |
|---|---|---|
| **Part Number** | Sanyo Denki 9GA0412P3K011 | Sanyo Denki 9GV0612P1G031 |
| **Frame Size** | 40mm × 40mm × 28mm | 60mm × 60mm × 38mm |
| **Voltage** | 12VDC (10.8–13.2VDC) | 12VDC (8–13.8VDC) |
| **Current** | 0.92A | 2.80A |
| **Power** | 11.04 W | 33.6 W |
| **Airflow** | 28.6 CFM (0.801 m³/min) | 84.0 CFM (2.35 m³/min) |
| **Static Pressure** | 3.21 in H₂O (800 Pa) | 3.02 in H₂O (752.3 Pa) |
| **Speed** | 22,000 RPM | 16,000 RPM |
| **Noise** | 61.0 dB(A) | 66.0 dB(A) |
| **Bearing Type** | Ball | Ball |
| **Termination** | 4 wire leads (PWM control, tach) | 4 wire leads (PWM control, tach) |
| **Operating Temp.** | -20°C ~ 70°C | -20°C ~ 70°C |
| **Datasheet** | [Sanyo Denki San Ace 40GA](https://publish.sanyodenki.com/library/books/San_Ace_E/book/#target/page=40GA28) | [Sanyo Denki San Ace 60GV](https://publish.sanyodenki.com/library/books/San_Ace_E/book/#target/page=60GV38) |

!!! note "Type B draws significantly more current"
    At 2.80A, the Type B fan draws roughly three times the current of the Type A fan (0.92A). Confirm the enclosure's power distribution and wiring are sized accordingly before swapping fan types between platforms.

### Commercial Sources

- **Type A Fan (9GA0412P3K011):** [digikey.com](https://www.digikey.com/en/products/detail/sanyo-denki-america-inc/9GA0412P3K011/6192261)
- **Type B Fan (9GV0612P1G031):** [digikey.com](https://www.digikey.com/en/products/detail/sanyo-denki-america-inc/9GV0612P1G031/6192369)

---

## Material Selection

Prototype ducts and fan mounts were printed in **PLA** for rapid iteration and geometry verification during early development. PLA's relatively low glass transition temperature and mechanical brittleness make it a poor long-term choice for components mounted near actively cooled electronics, however.

**PETG or ABS is recommended** for production units — both offer improved heat resistance, layer adhesion, and impact durability better suited to sustained operation inside the enclosure than PLA.

---

## Type A Duct

### CAD Bundles

<div class="download-cards" markdown>

<div class="download-card" style="--accent:#4A90D9;" markdown>
<span class="card-icon">:fontawesome-solid-draw-polygon:</span>

**SolidWorks Bundle**

Fan Mount, Airflow Duct (Standard & Short), and the Type A fan reference model, as native `.SLDPRT` files.

[Download](../media/Type_A/RIFTS_Duct_TypeA_SLDPRT_Bundle.zip){: .md-button :download}

</div>

<div class="download-card" style="--accent:#5CB85C;" markdown>
<span class="card-icon">:fontawesome-solid-diagram-project:</span>

**Neutral Bundle**

Same parts in `.STEP` format — works with most CAD software.

[Download](../media/Type_A/RIFTS_Duct_TypeA_STEP_Bundle.zip){: .md-button :download}

</div>

<div class="download-card" style="--accent:#E8833A;" markdown>
<span class="card-icon">:fontawesome-solid-cube:</span>

**STL Bundle**

Print-ready mesh geometry for all parts.

[Download](../media/Type_A/RIFTS_Duct_TypeA_STL_Bundle.zip){: .md-button :download}

</div>

</div>

### Print Projects

<div class="download-cards" markdown>

<div class="download-card" style="--accent:#8E5CD9;" markdown>
<span class="card-icon">:fontawesome-solid-print:</span>

**Standard**

RFSoC 4x2 length — Bambu Studio print project.

[Download](../media/Type_A/RIFTS_Duct_FanMount_AirflowDuct_TypeA_PrintAssembly.3mf){: .md-button :download}

</div>

<div class="download-card" style="--accent:#D9534F;" markdown>
<span class="card-icon">:fontawesome-solid-print:</span>

**Short**

ZCU216 length — Bambu Studio print project.

[Download](../media/Type_A/RIFTS_Short_Duct_FanMount_AirflowDuct_TypeA_PrintAssembly.3mf){: .md-button :download}

</div>

</div>

*A simplified reference model of the Type A fan's mounting footprint is included in the SolidWorks and Neutral Bundles above — see the note at the top of this page for details.*

### Assembly Hardware

Both the Standard and Short Type A duct assemblies require **four M3 × 50 mm machine screws and four M3 nuts** to secure the Fan Mount to the Airflow Duct.

### HD Renders

<div class="render-scroll" markdown>

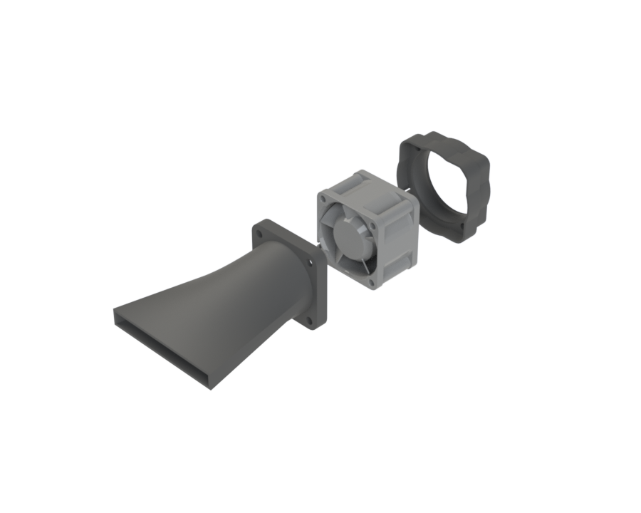
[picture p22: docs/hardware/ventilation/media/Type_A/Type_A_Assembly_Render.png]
Type A Render — Front


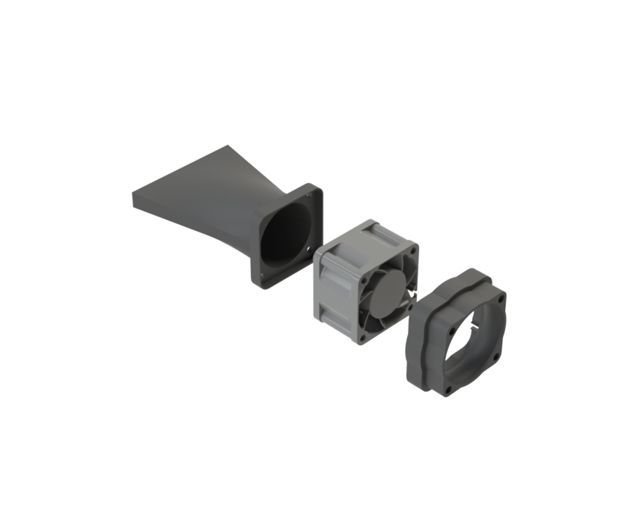
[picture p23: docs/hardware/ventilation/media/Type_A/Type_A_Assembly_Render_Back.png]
Type A Render — Back


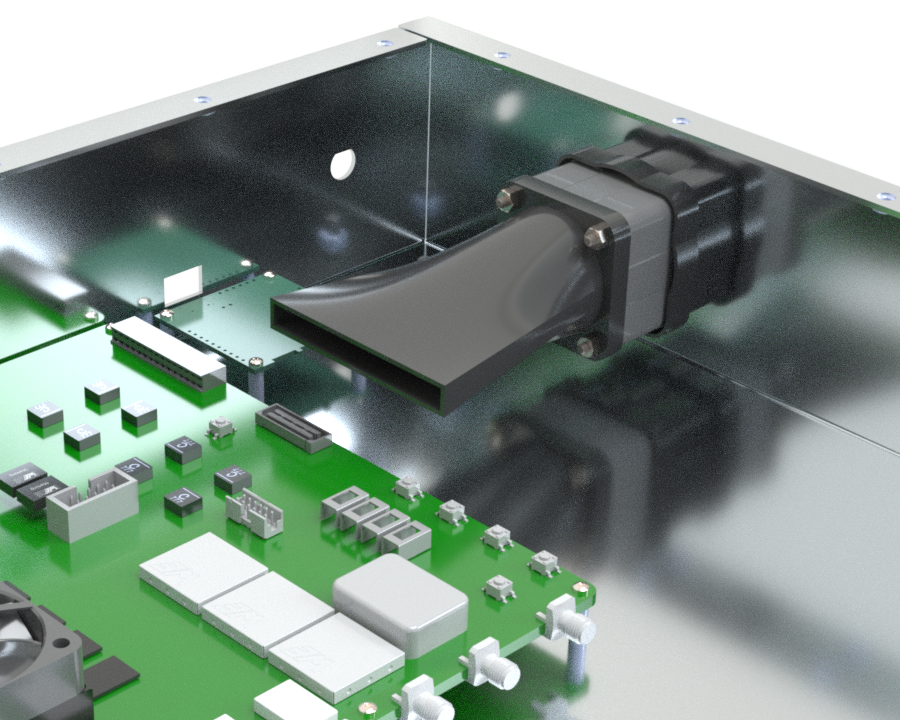
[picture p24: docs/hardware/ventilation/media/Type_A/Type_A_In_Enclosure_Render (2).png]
Type A Render — In Enclosure


Type A Render — Short Variant

</div>

---

## Type B Duct

### CAD Bundles

<div class="download-cards" markdown>

<div class="download-card" style="--accent:#4A90D9;" markdown>
<span class="card-icon">:fontawesome-solid-draw-polygon:</span>

**SolidWorks Bundle**

Fan Mount, Airflow Duct (Standard & Short), and the Type B fan reference model, as native `.SLDPRT` files.

[Download](../media/Type_B/RIFTS_Duct_TypeB_SLDPRT_Bundle.zip){: .md-button :download}

</div>

<div class="download-card" style="--accent:#5CB85C;" markdown>
<span class="card-icon">:fontawesome-solid-diagram-project:</span>

**Neutral Bundle**

Same parts in `.STEP` format — works with most CAD software.

[Download](../media/Type_B/RIFTS_Duct_TypeB_STEP_Bundle.zip){: .md-button :download}

</div>

<div class="download-card" style="--accent:#E8833A;" markdown>
<span class="card-icon">:fontawesome-solid-cube:</span>

**STL Bundle**

Print-ready mesh geometry for all parts.

[Download](../media/Type_B/RIFTS_Duct_TypeB_STL_Bundle.zip){: .md-button :download}

</div>

</div>

### Print Projects

<div class="download-cards" markdown>

<div class="download-card" style="--accent:#8E5CD9;" markdown>
<span class="card-icon">:fontawesome-solid-print:</span>

**Standard**

RFSoC 4x2 length — Bambu Studio print project.

[Download](../media/Type_B/RIFTS_Duct_FanMount_AirflowDuct_TypeB_PrintAssembly.3mf){: .md-button :download}

</div>

<div class="download-card" style="--accent:#D9534F;" markdown>
<span class="card-icon">:fontawesome-solid-print:</span>

**Short**

ZCU216 length — Bambu Studio print project.

[Download](../media/Type_B/RIFTS_Short_Duct_FanMount_AirflowDuct_TypeB_PrintAssembly.3mf){: .md-button :download}

</div>

</div>

*A simplified reference model of the Type B fan's mounting footprint is included in the SolidWorks and Neutral Bundles above — see the note at the top of this page for details.*

### Assembly Hardware

Both the Standard and Short Type B duct assemblies require:

- Four M3 × 15 mm machine screws and nuts
- Four M3 × 50 mm machine screws and nuts (minimum length — see note below)

!!! note "50 mm is a minimum, not a target — use longer screws on the Standard variant where possible"
    50 mm M3 screws only just barely protrude far enough past the assembly to fit the nuts on, which isn't ideal. The 50 mm cap is strictly a fit constraint of the **Short (ZCU216) variant** — the ZCU216 enclosure doesn't have room for anything longer. The **Standard (RFSoC 4x2) variant** has no such restriction and has room for longer screws, so screws longer than 50 mm should be used there whenever available. 50 mm is listed as the baseline/minimum length for both variants simply because it's guaranteed to work on either one.

!!! warning "Type B fan draws significantly more current — size wiring accordingly"
    The Type B fan (9GV0612P1G031) draws up to 2.80A at 12V (33.6W), roughly three times the current of the Type A fan (0.92A). Make sure any wiring, connectors, and fuse/PTC protection feeding the Type B duct assembly are rated for this before swapping fans between platforms or rewiring the enclosure — the Type A wiring gauge may not be adequate here.

### HD Renders

<div class="render-scroll" markdown>

Type B Render — Front

Type B Render — Back

Type B Render — In Enclosure

Type B Render — Short Variant

</div>

---

## Commercial Sources

- **M3 × 15 mm Machine Screws:** [mcmaster.com](https://www.mcmaster.com/products/screws/socket-head-screws-2~/system-of-measurement~metric/thread-size~m3/length~15-mm/)
- **M3 × 50 mm Machine Screws:** [mcmaster.com](https://www.mcmaster.com/products/screws/socket-head-screws-2~/system-of-measurement~metric/thread-size~m3/length~50-mm/)
- **M3 Nuts (Nylon Insert Locknuts):** [mcmaster.com](https://www.mcmaster.com/products/nuts/locknuts-2~/nylon-insert-locknuts-2~~/system-of-measurement~metric/thread-size~m3/)

!!! note "Locknuts recommended to resist loosening"
    The nuts linked above are nylon-insert locknuts, the same fastener type used for the sealing hardware on the [antenna mount page](../../antenna/nav_2/antenna-overview.md) — the nylon insert resists loosening under vibration over time better than a standard hex nut, which is worth having on hardware that sees repeated field transport and handling.

!!! note "Galvanic compatibility"
    Pairing dissimilar metals (e.g., stainless steel fasteners against an aluminum enclosure panel) can, under the right conditions, lead to galvanic corrosion over time. This isn't expected to be a meaningful concern here, since these enclosures aren't deployed in environments with sustained exposure to moisture or salt spray. Still, it's worth keeping galvanic compatibility in mind if this hardware is ever adapted for a more corrosion-prone deployment environment.

---

### Notes

- The **SolidWorks Bundle** (.zip) contains all `.SLDPRT` files for that duct type (Fan Mount, Standard Airflow Duct, Short Airflow Duct) along with the fan reference model. Requires SolidWorks to open.
- The **Neutral Bundle** (.zip) contains the same set of parts in `.STEP` format, compatible with most CAD software — recommended if you don't have access to SolidWorks.
- The **STL Bundle** (.zip) contains print-ready mesh geometry for all parts, for slicing in any FDM slicer.
- The **Print Project** (.3mf) files are Bambu Studio print projects containing the validated print settings and slicer profile — one for the Standard variant, one for the Short variant, since they're different length ducts.
- The **Short** variant uses the same Fan Mount as the Standard variant — only the Airflow Duct differs in length to fit inside the ZCU216 enclosure.
- The **fan reference models** (included in the SolidWorks and Neutral Bundles, one per duct type) are simplified stand-ins for the actual manufacturer fan — a block matching its true footprint and four-hole mounting pattern, without proprietary internal geometry. They're provided for enclosure packaging and mounting verification only, not as manufacturer-accurate CAD.

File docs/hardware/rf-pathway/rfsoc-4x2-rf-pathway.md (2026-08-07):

# RFSoC 4x2 RF Pathway Reference Model

## Project Summary

| | |
|---|---|
| **Project** | RFSoC 4x2 RF Pathway Reference Model |
| **Purpose** | Mechanical reference model for enclosure integration and layout validation |
| **Associated Hardware** | RFSoC 4x2 Portable Field Enclosure |
| **Model Type** | Reverse-engineered CAD reference model |
| **Estimated Accuracy** | Approximately 85% overall scale accuracy |
| **Intended Use** | Mechanical packaging and visualization |
| **Status** | Complete |

---

## Overview

The RFSoC 4x2 enclosure utilizes four RF signal pathways composed of commercially available RF components rather than a custom RF interface board. Because a complete mechanical CAD model of the pathway assembly wasn't available during enclosure development, this reference model was created to support internal packaging studies and mechanical integration.

This archive contains only the mechanically representative CAD model developed to support enclosure design. Four of these pathway assemblies are installed within the completed RFSoC 4x2 enclosure.

No complete CAD model was available, so the reference model was reverse engineered from a photograph of the assembled hardware, and a single measured overall pathway length. Individual RF components were modeled manually and proportionally scaled to approximately match that measured length — producing a mechanically representative model without requiring detailed dimensional data for every individual component.

**Suitable for:** mechanical packaging studies, enclosure layout, clearance verification, and CAD visualization.

**Not suitable for:** manufacturing, precision dimensional verification, mechanical tolerance analysis, RF simulation, or procurement.

The model prioritizes overall dimensions, connector locations, and approximate component placement — individual component geometries should not be considered dimensionally authoritative.

---

## Download

<div class="download-cards" markdown>

<div class="download-card" markdown>
<span class="card-icon">:fontawesome-solid-draw-polygon:</span>

**SLDPRT**

Native SolidWorks part file for the reference model.

[Download](../rf-pathway/rf_pathway.SLDPRT){: .md-button :download}

</div>

<div class="download-card" markdown>
<span class="card-icon">:fontawesome-solid-diagram-project:</span>

**STEP**

Neutral-format export compatible with most other CAD software.

[Download](../rf-pathway/rf_pathway.STEP){: .md-button :download}

</div>

</div>

---

## Gallery

<div class="compare-grid" markdown>

<div class="compare-item" markdown>
RF Pathway CAD
<p class="compare-label">Reference Model (CAD)</p>
</div>

<div class="compare-item" markdown>
RF Pathway Installed
<p class="compare-label">Installed Hardware</p>
</div>

</div>

Reverse-engineered CAD reference model alongside one of the four physical RF pathway assemblies installed within the completed RFSoC 4x2 enclosure.
{: .figure-caption }

---

## Associated Hardware Platform

This reference model was created specifically for integration into the [RFSoC 4x2 Portable Field Enclosure](../hardware/rfsoc-4x2/overview.md).

---

## Revision History

| Revision | Date | Description |
|---|---|---|
| Rev A | July 2026 | Initial RF pathway reference model documentation and archive release. |

---

## Credits

Reference model and documentation: **Joshua D'Addario**

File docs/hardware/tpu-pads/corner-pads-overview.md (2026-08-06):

# RFSoC 4x2 TPU Corner Pad System

## Project Summary

| | |
|---|---|
| **Project** | RFSoC 4x2 TPU Corner Pad System |
| **Purpose** | Protective corner assemblies for portable enclosure handling and transportation |
| **Associated Platform** | RFSoC 4x2 Portable Field Enclosure |
| **Manufacturing Method** | FDM Additive Manufacturing |
| **Primary Material** | TPU 95A HF|
| **Rigid Insert Material** | PLA Prototype / PETG Recommended |
| **Threaded Hardware** | M3 Brass Heat-Set Inserts |
| **Printer** | Bambu Lab A1 |
| **Status** | Complete |

---

## HD Renders

<div class="render-scroll" markdown>

Corner Pad 1 Render

Corner Pad 2 Render

Corner Pad 3 Render

Corner Pad 4 Render

</div>

*Renders are shown in order from Corner Pad 1 to Corner Pad 4, left to right.*

<!-- Add more renders by appending additional image lines above, same pattern. -->

---

## Overview

The RFSoC 4x2 TPU Corner Pad System was developed specifically for the portable RIFTS RFSoC 4x2 enclosure to improve durability during transportation, handling, and field deployment.

Unlike the laboratory-oriented ZCU216 enclosure, the RFSoC 4x2 platform was designed for repeated transportation and operation outside of a controlled laboratory environment. The corner pad assemblies provide mechanical protection for the aluminum enclosure.

This system was developed exclusively for the RFSoC 4x2 portable enclosure — these assemblies are not used on the ZCU216 enclosure platform.

---

## Design Overview

Each enclosure corner uses a **unique corner pad assembly** designed to accommodate the specific labeling of that corner. The complete system consists of four separate corner assemblies, each built from four TPU sections.

Each assembly contains:

| Item | Quantity |
|---|---|
| TPU Body Sections | 4 |
| Rigid Insert Components | 10 |
| M3 Brass Heat-Set Threaded Inserts | 10 |
| M3 × 10 mm Countersunk Machine Screws | 8 |
| M3 × 16 mm Countersunk Machine Screws | 2 |

The rigid insert components are glued into dedicated pockets within the TPU sections. Because TPU is flexible and does not provide an ideal material for directly installing heat-set inserts, rigid printed inserts were incorporated to provide a more reliable threaded interface. The heat-set inserts are installed into the rigid insert components, allowing the TPU sections to be mechanically fastened together into a complete three-dimensional corner pad assembly — a modular construction that allows damaged sections to be replaced individually rather than requiring replacement of an entire corner assembly.

The corner pad assemblies were developed to:

- Protect enclosure corners during transportation and handling.
- Reduce impact forces transferred to the aluminum enclosure.
- Provide a high-friction interface between the enclosure and supporting surfaces.
- Improve long-term durability of the portable hardware platform.

### Material Selection

The protective corner sections were manufactured using Thermoplastic Polyurethane (TPU), selected for high impact resistance, flexibility under loading, abrasion resistance, high surface friction, and the ability to absorb mechanical shocks. Compared with rigid thermoplastics, TPU provides improved energy absorption and reduces the likelihood of transmitting impact forces directly into the aluminum enclosure.

The rigid insert components were originally manufactured using PLA to support rapid prototyping and design iteration. For future manufacturing, **PETG is recommended** because it provides improved toughness, increased impact resistance, better elevated-temperature performance, and reduced brittleness during repeated assembly.

### Heat-Set Insert Installation

The M3 brass heat-set inserts are installed into the rigid printed insert components. Recommended installation procedure:

1. Heat a soldering iron to approximately **230°C - 250°C**.
2. Use a heat-set insert press attachment designed for soldering irons to maintain alignment during installation.
3. Insert the brass threaded insert into the prepared hole.
4. Ensure the **serrated face of the heat-set insert faces outward toward the opening of the hole** — the serrated surface should face upward/outward, not into the printed insert.
5. Apply heat and gently press the insert into position until fully seated.

Regardless of whether a standard soldering iron or a dedicated press is used, a soldering tip sized specifically for the insert's diameter is needed for a clean, controlled installation — a standard conical or chisel tip will not seat the insert evenly. See Commercial Sources below for the heat-set insert press and a sourced set of insert-sized tips; note that the press linked there already includes a set of these tips.

### Design Features

The completed corner pad assemblies provide full enclosure corner protection, replaceable modular construction, flexible impact absorption, increased friction against supporting surfaces, and lightweight construction. The modular design allows individual TPU sections or rigid inserts to be replaced without recreating the entire assembly.

### Assembly Tutorial

<div class="video-wrap" markdown="1">

<video controls>
  <source src="../rfsoc-4x2-corner-pads/RIFTS_Corner_Pad_1_Assembly_Tutorial.mp4" type="video/mp4">
  Your browser does not support the video tag.
</video>

SolidWorks walkthrough showing how the four TPU sections and rigid inserts assemble into one complete corner pad (shown using Corner Pad 1).
{: .video-caption }

</div>

### Installation Tutorial

<div class="video-wrap" markdown="1">

<video controls>
  <source src="../rfsoc-4x2-corner-pads/Corner_Pad_Installation_Tutorial.mp4" type="video/mp4">
  Your browser does not support the video tag.
</video>

SolidWorks walkthrough showing how a completed corner pad assembly mounts to the RFSoC 4x2 enclosure (shown using Corner Pad 4). Not applicable to the ZCU216 enclosure, which does not use this corner pad system.
{: .video-caption }

</div>

!!! note
    Since all four pads assemble and install identically, both procedures shown apply equally regardless of which pad you're working with.

### Corner Numbering Diagram

Corner Numbering Diagram

SolidWorks drawing labeling enclosure corners 1–4, showing which corner each pad is designed for.
{: .figure-caption }

### Installed Assembly

<div class="video-wrap" markdown="1">

<video controls>
  <source src="../rfsoc-4x2-corner-pads/Corner_Pads_Rotate_View.mp4" type="video/mp4">
  Your browser does not support the video tag.
</video>

SolidWorks rotating view showing all four corner pads installed on the RFSoC 4x2 enclosure — cross-reference with the numbering diagram above to identify which pad goes where.
{: .video-caption }

</div>

<!-- TODO: confirm final video filename once uploaded -->

---

## Downloads

Downloadable CAD and manufacturing files for all four unique corner assemblies (Section A, Section B, Section C, and Section D) and the shared rigid insert component.

!!! note
    Each bundle below packages that pad's four sections together with the rigid insert files in the matching format, so you only need to grab one zip per format instead of downloading each part individually. The **SolidWorks Bundle** includes the `.SLDASM` full assembly file alongside the individual `.SLDPRT` parts — no separate assembly download needed. The **Print Bundle** likewise includes the `.3mf` for all four sections plus the rigid insert's `.3mf`.

<div class="download-cards cols-2" markdown>

<div class="download-card" markdown>
<span class="card-icon">:fontawesome-solid-cubes:</span>

**Corner Pad 1**

[:fontawesome-solid-draw-polygon: SLDPRT](rfsoc-4x2-corner-pads/Corner_Pad_1/RIFTS_CornerPad_1_SLDPRT_Bundle.zip){: .card-action title="SolidWorks Bundle (.zip) — includes .SLDASM" }
[:fontawesome-solid-diagram-project: STEP](rfsoc-4x2-corner-pads/Corner_Pad_1/RIFTS_CornerPad_1_STEP_Bundle.zip){: .card-action title="Neutral Bundle (.zip)" }
[:fontawesome-solid-cube: STL](rfsoc-4x2-corner-pads/Corner_Pad_1/RIFTS_CornerPad_1_STL_Bundle.zip){: .card-action title="Print-Ready Bundle (.zip)" }
[:fontawesome-solid-print: 3MF](rfsoc-4x2-corner-pads/Corner_Pad_1/RIFTS_CornerPad_1_Print_Bundle.zip){: .card-action title="Bambu Studio Print Bundle (.zip)" }
{: .card-actions-row }

</div>

<div class="download-card" markdown>
<span class="card-icon">:fontawesome-solid-cubes:</span>

**Corner Pad 2**

[:fontawesome-solid-draw-polygon: SLDPRT](rfsoc-4x2-corner-pads/Corner_Pad_2/RIFTS_CornerPad_2_SLDPRT_Bundle.zip){: .card-action title="SolidWorks Bundle (.zip) — includes .SLDASM" }
[:fontawesome-solid-diagram-project: STEP](rfsoc-4x2-corner-pads/Corner_Pad_2/RIFTS_CornerPad_2_STEP_Bundle.zip){: .card-action title="Neutral Bundle (.zip)" }
[:fontawesome-solid-cube: STL](rfsoc-4x2-corner-pads/Corner_Pad_2/RIFTS_CornerPad_2_STL_Bundle.zip){: .card-action title="Print-Ready Bundle (.zip)" }
[:fontawesome-solid-print: 3MF](rfsoc-4x2-corner-pads/Corner_Pad_2/RIFTS_CornerPad_2_Print_Bundle.zip){: .card-action title="Bambu Studio Print Bundle (.zip)" }
{: .card-actions-row }

</div>

<div class="download-card" markdown>
<span class="card-icon">:fontawesome-solid-cubes:</span>

**Corner Pad 3**

[:fontawesome-solid-draw-polygon: SLDPRT](rfsoc-4x2-corner-pads/Corner_Pad_3/RIFTS_CornerPad_3_SLDPRT_Bundle.zip){: .card-action title="SolidWorks Bundle (.zip) — includes .SLDASM" }
[:fontawesome-solid-diagram-project: STEP](rfsoc-4x2-corner-pads/Corner_Pad_3/RIFTS_CornerPad_3_STEP_Bundle.zip){: .card-action title="Neutral Bundle (.zip)" }
[:fontawesome-solid-cube: STL](rfsoc-4x2-corner-pads/Corner_Pad_3/RIFTS_CornerPad_3_STL_Bundle.zip){: .card-action title="Print-Ready Bundle (.zip)" }
[:fontawesome-solid-print: 3MF](rfsoc-4x2-corner-pads/Corner_Pad_3/RIFTS_CornerPad_3_Print_Bundle.zip){: .card-action title="Bambu Studio Print Bundle (.zip)" }
{: .card-actions-row }

</div>

<div class="download-card" markdown>
<span class="card-icon">:fontawesome-solid-cubes:</span>

**Corner Pad 4**

[:fontawesome-solid-draw-polygon: SLDPRT](rfsoc-4x2-corner-pads/Corner_Pad_4/RIFTS_CornerPad_4_SLDPRT_Bundle.zip){: .card-action title="SolidWorks Bundle (.zip) — includes .SLDASM" }
[:fontawesome-solid-diagram-project: STEP](rfsoc-4x2-corner-pads/Corner_Pad_4/RIFTS_CornerPad_4_STEP_Bundle.zip){: .card-action title="Neutral Bundle (.zip)" }
[:fontawesome-solid-cube: STL](rfsoc-4x2-corner-pads/Corner_Pad_4/RIFTS_CornerPad_4_STL_Bundle.zip){: .card-action title="Print-Ready Bundle (.zip)" }
[:fontawesome-solid-print: 3MF](rfsoc-4x2-corner-pads/Corner_Pad_4/RIFTS_CornerPad_4_Print_Bundle.zip){: .card-action title="Bambu Studio Print Bundle (.zip)" }
{: .card-actions-row }

</div>

</div>

### Additional Downloads

<div class="download-cards" markdown>

<div class="download-card" markdown>
<span class="card-icon">:fontawesome-solid-layer-group:</span>

**All Pads**

Single `.3mf` with 4 print plates, one per pad — cycle through in Bambu Studio to print the full set.

[Download](rfsoc-4x2-corner-pads/RIFTS_CornerPads_All_Print_Bundle.3mf){: .md-button :download}

</div>

<div class="download-card" markdown>
<span class="card-icon">:fontawesome-solid-file-zipper:</span>

**Rigid Insert Only**

The shared insert component alone, in every format — no need to open a full pad bundle to get it.

[Download](rfsoc-4x2-corner-pads/RIFTS_CornerPad_Rigid_Insert_Bundle.zip){: .md-button :download}

</div>

</div>

### Notes

- Each **SolidWorks Bundle** (SLDPRT) contains four `.SLDPRT` files (Sections A–D), the rigid insert `.SLDPRT`, **and the `.SLDASM` full assembly file** — everything needed to open the complete assembly is in this one zip. Requires SolidWorks to open.
- Each **Neutral Bundle** (STEP) contains the same set of parts in `.STEP` format, compatible with most CAD software — recommended if you don't have access to SolidWorks.
- Each **Print-Ready Bundle** (STL) contains print-ready mesh geometry for all four sections plus the rigid insert, for slicing in any FDM slicer.
- Each **Print Bundle** (3MF) contains the `.3mf` files for all four sections plus the rigid insert, each preserving the validated print settings and slicer profile used for production. Opening them requires Bambu Studio.
- **All Pads** is a single `.3mf` file containing four separate print plates, one per corner pad.
- **Rigid Insert Only** provides just the shared insert component on its own, in every format, without needing to open a full pad bundle to get it.

---
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

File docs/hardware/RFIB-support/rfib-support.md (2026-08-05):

# RF Interface Board (RFIB) Support

## Project Summary

| | |
|---|---|
| **Project** | RF Interface Board (RFIB) Support |
| **Purpose** | Structural support bridging the RF Interface Board's widely spaced mounting points, while enabling internal cable routing |
| **Associated Platform** | ZCU216 RF Shielded Enclosure |
| **Manufacturing Method** | FDM Additive Manufacturing |
| **Primary Material** | PLA (as manufactured) |
| **Recommended Material** | PETG (improved thermal performance) |
| **Mounting** | Shares the RF Interface Board's existing 3 mounting standoffs |
| **Construction** | Two-piece, glued |
| **Status** | Complete |

---

## HD Renders

<div class="render-scroll" markdown>

RFIB Support Render 1

RFIB Support Render 2

RFIB Support Render 3

RFIB Support Render 3

RFIB Support Render 3

</div>

<!-- Scroll strip — add more renders by appending additional image lines above, same pattern. -->

---
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

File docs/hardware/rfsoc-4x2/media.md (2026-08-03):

# Enclosure CAD

Downloadable CAD model of the completed RFSoC 4x2 Portable Field Enclosure — the final production design, built from 0.064 in seam-welded 5052 aluminum with dual forced-air cooling, including a heatsink-mounted exhaust fan for direct RFSoC thermal management.

---

## Downloads

<div class="download-cards" markdown>

<div class="download-card" markdown>
<span class="card-icon">:fontawesome-solid-diagram-project:</span>

**STEP**

Neutral-format export compatible with SolidWorks, Fusion 360, OnShape, and most other CAD software.

[Download](../../media/rfsoc-4x2/RIFTS_RFSoC_4x2_Enclosure.STEP){: .md-button :download}

</div>

<div class="download-card" markdown>
<span class="card-icon">:fontawesome-solid-compass-drafting:</span>

**Protocase Designer**

The exact fabrication package (.pda) submitted for manufacturing — opens in Protocase's free design software.
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

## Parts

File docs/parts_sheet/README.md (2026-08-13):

FLASH-MEP parts sheet https://docs.google.com/spreadsheets/d/1aVYJW8B82nQ8EhuhUXIeyBJPT4pah5DBl2TXt3p7wDM/edit?gid=0#gid=0

https://www.analog.com/en/resources/evaluation-hardware-and-software/evaluation-boards-kits/scp-lt3045-1-evalz.html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

https://www.digikey.com/en/products/detail/amphenol-rf/242106/1012007

https://www.evissap.com/sma-male-to-tnc-male-lmr195-cable-assembly.html

https://www.blackanddecker.com/products/lcs1620b

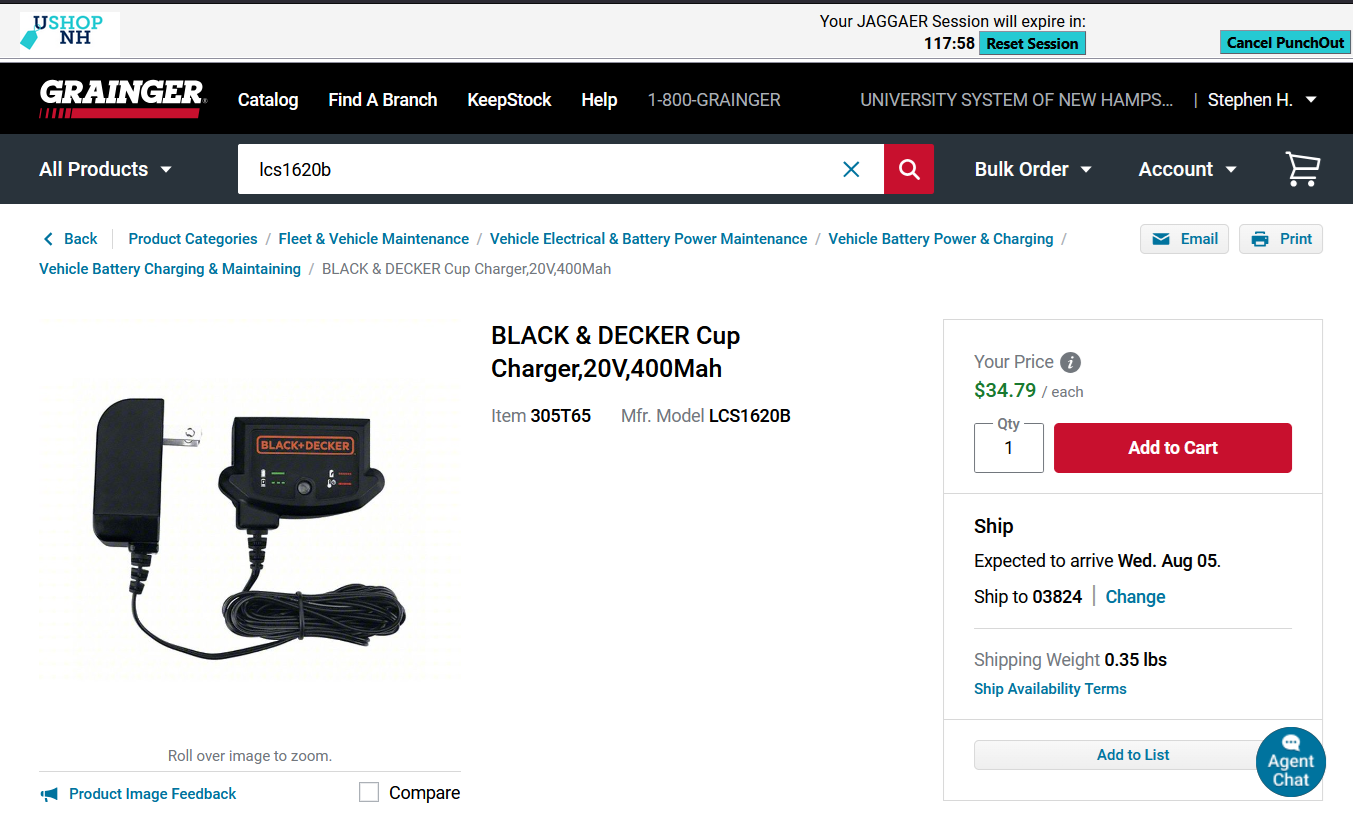
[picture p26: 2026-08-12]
docs/parts_sheet/grainger_bd_charger.png

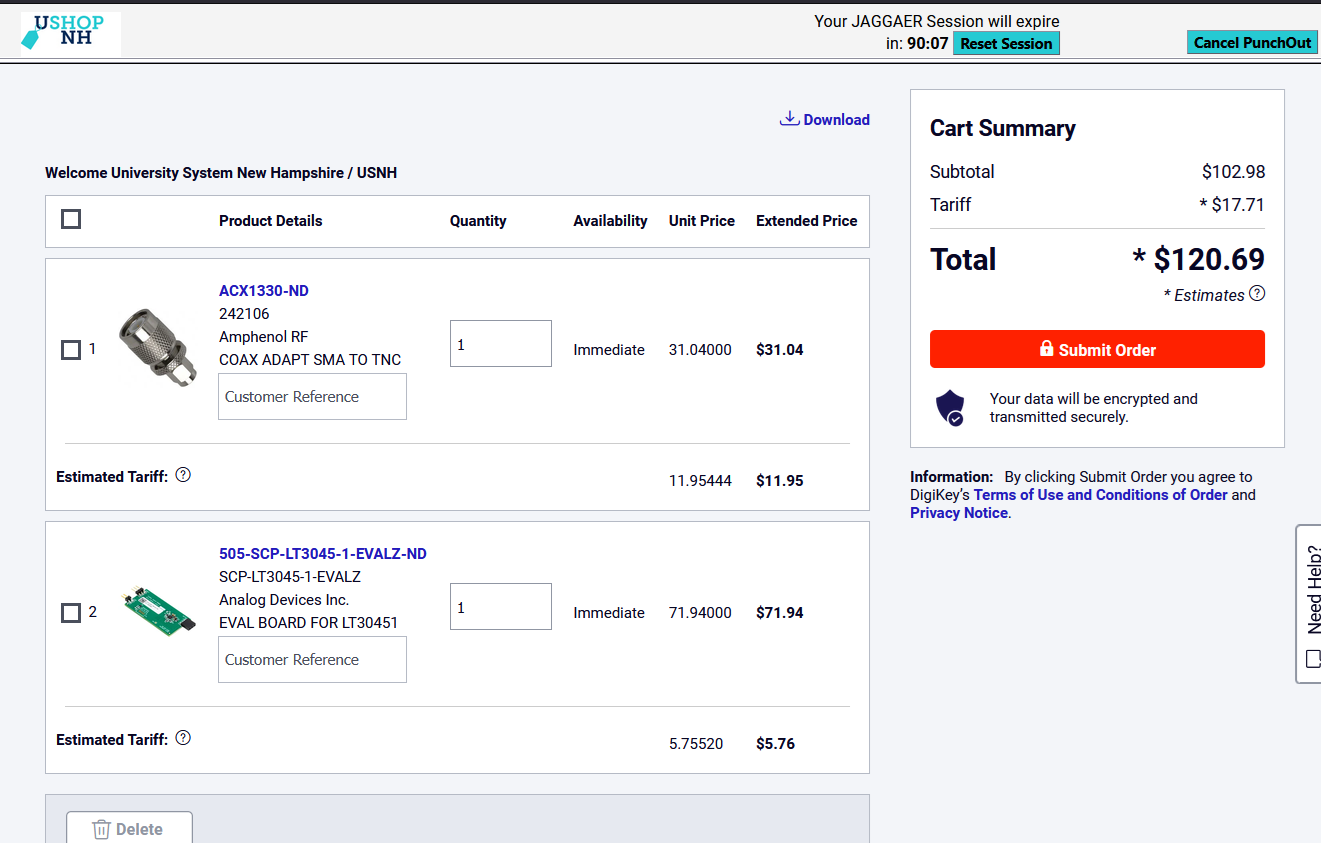
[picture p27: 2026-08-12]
docs/parts_sheet/Ushop_portal_2026-08-03T151505.png

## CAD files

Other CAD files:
docs/media/antenna-mount/RIFTS_WaterImmersion_FixtureSupport_PrintPackage.3mf
docs/media/antenna-mount/RIFTS_WaterImmersion_FixtureSupport.STL

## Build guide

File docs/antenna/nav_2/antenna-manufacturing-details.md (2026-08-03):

# Manufacturing Details

Full build reference for the OmniLOG PRO 1030 N Antenna Mount System — validated print parameters and the complete bill of materials needed to assemble one unit.

---

## Bill of Materials

The assembly consists of three primary FDM-printed components, commercial sealing hardware, stainless steel fasteners, and ground mounting hardware. Quantities listed represent the requirements for one complete antenna mount assembly.

| Item | Quantity | Description | Notes |
|---|---|---|---|
| Top Lid | 1 | FDM printed component | Provides antenna mounting interface and O-ring sealing surface |
| Cylindrical Housing | 1 | FDM printed component | Houses antenna electronic stem and provides environmental enclosure |
| Ground Mounting Mast | 1 | FDM printed component | Provides ground stake interface and structural support |
| O-ring | 1 | 50 mm × 3.5 mm (ID × CS) | Commercially sourced sealing element |
| M16L Waterproof Cable Gland | 1 | Waterproof cable entry fitting | Provides sealed cable routing through enclosure |
| M5 Stainless Steel Flanged Button Head Screws | 6 | Minimum 25 mm length | Secures top lid to cylindrical housing; flange helps prevent long-term creep of the printed lid |
| M5 Stainless Steel Flange Nuts (Nylon Insert) | 6 | Locking type | Used with lid fasteners; flange eliminates the need for a separate washer |
| M5 Brass Heat-set Inserts | 2 | Minimum 6 mm length recommended | Installed in mounting mast for housing attachment |
| Ground Stakes | 2 | Minimum 8 in length, 3/8 in - 1/2 in diameter recommended | Used for field deployment anchoring |
| Ground Stake Washers | 2 | Load distribution washers | Reduces localized compressive loading |

!!! note
    For the material evolution across prototype, field-evaluation, and final production versions (PLA → ABS → ASA-CF), see Design Evolution on the main Overview page.

### Fastener Notes

**Lid Fasteners** — The top lid is secured to the cylindrical housing using six M5 stainless steel flanged button head screws and six M5 flange nuts (nylon insert type). The flange on each screw helps prevent long-term deformation (creep) of the 3D-printed top lid, and the flange on each nut eliminates the need for a separate washer. A minimum screw length of 25 mm is recommended to provide sufficient engagement through the lid and housing interface. Fasteners should be tightened in a star pattern to apply even compression across the O-ring seal. Note that the nylon insert in each flange nut wears with repeated use and should only be reused a handful of times before replacement.

**Mast Inserts** — The cylindrical housing attaches to the ground mounting mast through two M5 brass heat-set inserts installed into the printed mast component. A minimum insert length of approximately 6 mm is recommended; insert length has not been found to be a critical design parameter provided sufficient engagement is achieved.

### Heat-Set Insert Installation

The two M5 brass heat-set inserts used in the mounting mast are installed after printing. Recommended procedure:

1. Heat a soldering iron to approximately **230°C - 250°C**.
2. Orient the brass heat-set insert so the **serrated face is facing outward from the printed part** (toward the ceiling during installation), with the smooth face entering the printed hole first — the serrated face should **not** point down into the hole.
3. Carefully press the heat-set insert into the prepared hole while applying controlled downward pressure.
4. Allow the surrounding plastic to cool and solidify around the insert before applying mechanical load.

Proper insert orientation matters — installing the insert upside down may reduce mechanical retention, since the serrated surface is intended to embed into the surrounding plastic and resist pull-out forces. A heat-set insert press can improve alignment and consistency.

Regardless of whether a standard soldering iron or a dedicated press is used, a soldering tip sized specifically for the insert's diameter is needed for a clean, controlled installation — a standard conical or chisel tip will not seat the insert evenly. See Commercial Sources below for a sourced set of insert-sized tips; note that the heat-set insert press linked there already includes a set of these tips.

### Commercial Sources

- **Cable Gland:** QILIPSU M16L Waterproof Cable Gland — [amazon.com](https://www.amazon.com/QILIPSU-Thread-Waterproof-Through-Connector/dp/B0F99JGRYY)
- **Heat-Set Insert Press:** Vertical Heat Insert Press Attachment for Soldering Iron — [amazon.com](https://www.amazon.com/Vertical-Machine-Heat-Insertion-Threaded-Components/dp/B0DHKPHKJZ)
- **Soldering Tips (Insert-Sized Assortment):** Dedicated tips sized for heat-set insert installation; note the heat-set insert press linked above already includes a set of these tips - [amazon.com](https://www.amazon.com/HANGLIFE-Heat-Set-Soldering-Compatible-Components/dp/B0CS662NVK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)
- **Threaded Inserts:** Brass Heat-Set M5 Threaded Inserts — [amazon.com](https://www.amazon.com/Pofsnnx-80PCS-Threaded-Inserts-Assortment/dp/B0FJXP9LBM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)
- **Silicone Grease:** Molykote 111 — [amazon.com](https://www.amazon.com/Molykote-Lubricant-Components-Resistant-Volatility/dp/B0DYDFLXGZ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)
- **O-Ring (Fluoroelastomer):** 75 Durometer Fluoroelastomer O-Ring, 50 mm ID × 3.5 mm CS, rated to −15 °F — [callapg.com](https://callapg.com/fluoroelastomer-75-durometer-o-ring-50-mm-id-x-35-mm-cs-v35x50)
- **Lid/Housing Fasteners:** Stainless Steel Flanged Button Head Hex Drive Screws — [mcmaster.com](https://www.mcmaster.com/products/screws/rounded-head-screws-2~/stainless-steel-flanged-button-head-hex-drive-screws~~/)
- **Lid/Housing Nuts:** Flange Nuts, Nylon Insert Type — [mcmaster.com](https://www.mcmaster.com/products/nuts/flange-nuts-4~/flange-nuts-4~locking-type~nylon-insert/)
- **Ground Stakes (Standard):** Stainless Steel Hex Head Wood Lag Screws — [mcmaster.com](https://www.mcmaster.com/products/lag-screws/stainless-steel-hex-head-wood-screws~~/)
- **Washers, Standard Stakes:** General Purpose Corrosion-Resistant Washers — [mcmaster.com](https://www.mcmaster.com/products/washers/general-purpose-washers-3~~/washers-2~performance~corrosion-resistant-2/)
- **Ground Stakes (Upgrade):** 1/2" Rebar Ground Stakes — [amazon.com](https://www.amazon.com/s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)

!!! note "O-ring material: fluoroelastomer, not silicone"
    Silicone is generally the preferred O-ring material for cold-weather flexibility, but a silicone O-ring matching the required dimensions (50 mm ID × 3.5 mm CS) could not be readily sourced. The fluoroelastomer O-ring linked above is rated to −15 °F, which should provide reasonably solid cold-weather performance for New England winters, and was selected as the practical substitute given sourcing constraints.

!!! note "Ground stakes: standard vs. upgrade"
    Lag screws with washers are the **standard/stock** ground stake option — cheaper, and proven to work reliably. Rebar ground stakes are an **optional upgrade** for a more permanent or robust field installation, not a required change.

---

## Print Settings

Validated FDM printing parameters used during development, manufactured and evaluated on a **Bambu Lab A1**. These represent the configurations used during prototype development and field evaluation — future reproductions may use equivalent hardware and materials, but maintaining similar print parameters is recommended to preserve mechanical performance and dimensional accuracy.

### Printer

| Parameter | Value |
|---|---|
| Printer | Bambu Lab A1 |
| Nozzle | 0.4 mm Stainless Steel |
| Slicer | Bambu Studio |
| Layer Height | 0.20 mm |

### Filament

| Material | Application |
|---|---|
| Bambu PLA Basic | Initial prototype development and geometry verification |
| Bambu ABS | Field evaluation prototypes |
| Bambu ASA-CF | Final production design — improved UV resistance and long-term outdoor durability |

For future prints using Bambu Lab printers, Bambu brand filament is recommended where possible; equivalent materials from other manufacturers may also be suitable if comparable mechanical and thermal properties are maintained.

### Print Orientation

Print orientation was selected to reduce support requirements, preserve critical sealing surfaces, and maintain mechanical strength.

**Top Lid** — Printed with the O-ring sealing groove facing upward. This allows the groove to be printed without support material, preserving a clean sealing surface — avoiding supports here matters because imperfections in this region could negatively impact sealing performance.

**Cylindrical Housing** — Printed with the lid sealing face oriented downward toward the print bed. This minimizes required supports; the antenna stem cavity at the bottom of the housing requires only a single support tree structure, whereas the opposite orientation would require significantly more support material for the overhanging sealing face. This balances support material usage, surface quality, print reliability, and preservation of sealing geometry.

**Ground Mounting Mast** — Printed vertically, standing upright with the M5 heat-set insert mounting holes facing upward. This follows the natural loading direction of the component and requires no supports.

### Structural Settings

| Parameter | Value |
|---|---|
| Wall Loops | 12 |
| Top/Bottom Surface Pattern | Concentric |
| Top/Bottom Shell Thickness | 1.6 mm |
| Top/Bottom Shell Layers | 8 |
| Internal Solid Infill Pattern | Monotonic |
| Sparse Infill Density | 30% |
| Sparse Infill Pattern | Gyroid |

### Support Settings

| Parameter | Value |
|---|---|
| Support Style | Tree Slim |
| Support Generation | Tree Auto |
| Overhang Threshold Angle | 55° |
| Top Z Distance | 0.28 mm |
| Interface Layers | 3 |

Tree supports were selected to minimize unnecessary material usage and reduce surface defects on externally visible surfaces.

!!! note
    The `.3mf` project files (see Media) preserve the exact Bambu Studio configuration — orientation, supports, material, and slicing parameters — used for production. When reproducing this design, using the provided `.3mf` files is recommended when a compatible Bambu printer is available.

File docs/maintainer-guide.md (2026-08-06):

# Maintainer Guide

<div class="maintainer-badge">Maintainer Documentation — Not RIFTS Hardware Content</div>

<div class="maintainer-page" markdown="1">

This page exists so that anyone besides the original author can pick up
this site, run it locally, and add new content without having to
reverse-engineer how it works.

---

## 1. What This Site Is

A MkDocs (Material theme) static site documenting RIFTS mechanical hardware —
enclosures, antenna mounts, supporting hardware, and CAD references. It's
plain Markdown files plus a small custom stylesheet, built into static HTML
and published automatically.

## 2. Software You'll Need

Install these once per computer, in this order, before doing anything else.
Everything here is free.

| Tool | What it's for | Download |
|---|---|---|
| **Git** | Tracks changes to the files and talks to GitHub | [git-scm.com/downloads](https://git-scm.com/downloads) |
| **Git LFS** | Handles the large CAD file bundles in this repo (see note below — skip this and downloads will look broken) | [git-lfs.com](https://git-lfs.com/) |
| **Python 3** | Runs MkDocs, which builds the site | [python.org/downloads](https://www.python.org/downloads/) |
| **A code editor** | For editing Markdown/YAML files — plain Notepad works but is painful | [Visual Studio Code](https://code.visualstudio.com/download) (recommended, free) |

On Windows, installing **Git for Windows** also gives you "Git Bash," a
terminal that behaves like Mac/Linux — use that instead of Command Prompt for
any commands in this guide.

!!! warning "Don't skip Git LFS"
    This repo stores its large CAD file bundles (the SolidWorks/STEP/STL
    downloads) through **Git LFS** instead of directly in Git, because Git
    itself handles large binary files poorly. If you clone this repo
    *without* Git LFS installed first, those CAD downloads will silently be
    replaced by tiny broken placeholder files — nothing will error, the
    download links will just be broken. Install it and run
    `git lfs install` (see Section 4) before you clone.

### An easier alternative to the command line: GitHub Desktop

Everything in this guide can be done from a terminal, but if that's
unfamiliar territory, **[GitHub Desktop](https://desktop.github.com/)** is a
free app that does the clone/commit/push steps through buttons and a visual
diff viewer instead of typed commands. It **automatically handles Git LFS**
for you — one less thing to install and remember. It doesn't replace the
code editor (you'd still open the files in VS Code to actually write
content) but it removes almost all of the "typing git commands correctly"
friction.

If you install GitHub Desktop, you can skip the `git clone` command in
Section 4 below — use **File → Clone Repository** in the app instead, sign
in with your GitHub account when prompted, and pick this repo from the
list.

---

## 3. Repository & Hosting Access

The site is hosted on **GitHub Pages**, built and deployed via **GitHub
Actions** — every push to the main branch triggers an automatic rebuild and
redeploy. There is no manual deploy step.

### Recommended: move the repo into a GitHub Organization

**Do this rather than just adding people as collaborators on your personal
account.** A personal account is tied to one person — if that account is
ever deleted, renamed, or simply inaccessible, everything under it (repo,
Pages site, Actions history) goes with it. An organization is its own
independent entity that any current or future RIFTS team member can belong
to, so the project survives graduations, role changes, and anyone's
individual account problems. For a project meant to outlive any one
student's time at UNH, this is the right home for it, not an optional
upgrade.

1. Create the org (free) at [github.com/organizations/new](https://github.com/organizations/new) —
   something like `unh-rifts` is a reasonable name.
2. In the repo → **Settings → General → Danger Zone → Transfer ownership** →
   transfer it into the new org.
3. In the org → **People → Invite member** → add whoever will be
   maintaining the site (and yourself, so you keep access after you're no
   longer the account owner). Give them at least **Write** access to the
   repo; **Admin** if they should also manage repo/org settings.
4. Each person invited gets an email invitation — **they need to accept
   it** before they have any access at all. Nothing below in this guide
   works for them until that invite is accepted.

Nothing about the site, the Pages URL, or the Actions workflow needs to
change when you do this — only who owns the repo.

### Faster stopgap, if you need access set up today

If the org move needs to wait, you can add someone directly to your
personal repo instead: **Settings → Collaborators and teams → Add people**,
same Write/Admin choice as above, same email-invite-must-be-accepted step.
This works immediately but should be treated as temporary — plan to do the
org transfer above once there's time, rather than leaving it as the
permanent setup.

**One thing to verify either way:** open `.github/workflows/` and confirm the
deploy workflow only uses the default `GITHUB_TOKEN`. If it references a
personal access token or secret tied to one specific account, that'll need
to be replaced or other maintainers' pushes won't deploy.

---

## 4. Local Development Setup

Two ways to get the files onto your computer — pick whichever matches what
you installed in Section 2.

### Option A: GitHub Desktop (recommended if the command line feels unfamiliar)

**Before this will work, you need to already have access to the repo** —
that means you must have received and *accepted* an invite (either as an
org member or a direct collaborator, per Section 3). Check your email for a
GitHub invitation if you're not sure — until it's accepted, the repo won't
show up anywhere in GitHub Desktop no matter what you try.

1. If you don't already have a GitHub account, create one free at
   [github.com/join](https://github.com/join) — you'll need this before an
   invite can even be sent to you.
2. Open GitHub Desktop → **File → Clone Repository**.
3. Sign in with that same GitHub account when prompted.
4. Click the correct tab — **GitHub.com** for a personal-account repo, or
   **your org's name** (e.g. `unh-rifts`) if it's been moved into an
   organization — and the repo should now appear in the list, since you
   have access.
5. Select it, choose a folder on your computer, click **Clone**. Git LFS is
   handled automatically — nothing else to do here.
6. Open a terminal *inside that cloned folder* (in GitHub Desktop:
   **Repository → Open in Terminal**) and run just the Python/MkDocs part
   below, starting from `python3 -m venv .venv`.

### Option B: Command line

Run once per machine, before your first clone:

```bash
git lfs install       # one-time setup per machine
```

Then, once per project:

```bash
git clone <repo-url>
cd <repo-folder>
python3 -m venv .venv
source .venv/bin/activate      # Windows (Git Bash): source .venv/Scripts/activate
pip install -r requirements.txt
```

### Previewing the site (either option)

From inside the project folder, with the virtual environment active:

```bash
mkdocs serve                   # live preview at http://127.0.0.1:8000
```

Open that address in a browser — it auto-reloads every time you save a file,
so you can see your edits immediately without pushing anything yet. Leave
this running in its own terminal window while you work; open a second
terminal (or GitHub Desktop) for git commands.

Running `mkdocs build` (optional) is a good sanity check before pushing — it
surfaces broken links or bad Markdown the same way the real Actions build
would, without waiting on CI to tell you.

Pushing to the main branch is what actually publishes the site — there is no
separate manual deploy command to run.

---

## 5. Day-to-Day Editing Workflow

Once everything in Sections 2–4 is set up, every future edit — big or
small — follows the same repeating loop: **get the latest version → make
your change → check it looks right → save your change → send it up to
GitHub.**

Follow whichever section below matches what you set up in Section 4. Do the
steps in order, every time — skipping the "get latest" step at the start is
the most common way people run into confusing conflicts later.

### If you're using GitHub Desktop

1. Open the **GitHub Desktop** app. Confirm the correct repository is
   selected — its name appears near the top-left of the window; if it's
   the wrong one, click that name to switch.
2. Click **Fetch origin** in the top bar. GitHub Desktop checks whether
   anyone else has pushed changes since you last opened it.
3. If a **Pull origin** button appears after that, click it too, and wait
   for it to finish downloading. (If it stays as "Fetch origin" with no
   "Pull" button showing up, you're already fully up to date — move on.)
4. Open the project folder on your computer (wherever you cloned it) and
   open the `.md` file you want to edit in your code editor.
5. Make your edits, then **save the file** (Ctrl+S / Cmd+S).
6. Switch to the browser tab running your `mkdocs serve` preview (see
   Section 4) and refresh it. Confirm your change actually looks right
   before going further.
7. Switch back to GitHub Desktop. Your edited file(s) now appear in a list
   on the left, under **Changes** — this is everything that's different
   from what's currently live on GitHub.
8. In the text box at the bottom-left, type a short description of what
   you changed — e.g. "Update ZCU216 overview wording." This becomes the
   commit's label, so anyone looking at the project's history later can
   tell what happened and why.
9. Click **Commit to main**.
10. Click **Push origin** in the top bar. This uploads your commit to
    GitHub — watch for the small progress indicator to confirm it finished.
11. Done editing for now. Skip to **Confirming it worked** below.

### If you're using the command line

1. Open your terminal and move into the project folder, if you're not
   already there:
   ```bash
   cd path/to/project-folder
   ```
2. Pull the latest changes:
   ```bash
   git pull
   ```
   This downloads anything others have pushed since you last checked. If it
   reports a conflict, stop and don't guess — that means someone edited the
   same lines you're about to touch, and needs to be resolved carefully.
3. Open the `.md` file you want to edit in your code editor, make your
   changes, and save it.
4. Check your `mkdocs serve` preview (Section 4) in the browser — refresh
   the page and confirm the change actually looks right.
5. Stage your changes (marks them as ready to be recorded):
   ```bash
   git add .
   ```
6. Commit them, with a short description of what changed:
   ```bash
   git commit -m "short description of the change"
   ```
7. Push them up to GitHub:
   ```bash
   git push
   ```
8. Done editing for now. Continue to **Confirming it worked** below.

### Confirming it worked (either method)

1. On GitHub.com, open the repo and click the **Actions** tab near the top
   of the page.
2. Find the most recent run at the top of the list — a green checkmark
   means the site rebuilt and published successfully. A red ✕ means it
   failed; click into that run to see the error log explaining why (almost
   always a Markdown or YAML typo).
3. Give it a minute or two after pushing, then open the live site and hard
   refresh (Ctrl+Shift+R / Cmd+Shift+R) to make sure you're not looking at
   a cached older version.

---

## 6. Site Structure

- `mkdocs.yml` — site config and the left-hand navigation tree. **Adding a
  new page requires two steps**: create the `.md` file under `docs/`, *and*
  add an entry for it under `nav:` in `mkdocs.yml` — pages not listed in
  `nav` won't appear in the sidebar even if they exist.
- `docs/stylesheets/extra.css` — all custom styling, including the
  conventions below.
- Each hardware platform generally follows the same page skeleton: Project
  Summary table → HD Renders → Overview → Design Rationale → Manufacturing
  → Engineering Notes → Lessons Learned → Future Work → Related Hardware →
  Revision History → Credits. Copying an existing page (e.g.
  `hardware/zcu216/overview.md`) as a starting template is the easiest way
  to keep new pages consistent.

---

## 7. Styling Conventions (Copy-Paste Patterns)

These are the established patterns on this site. Reuse them exactly for new
pages so everything stays visually consistent — don't reinvent per-page.

### Image with caption

```markdown
![Alt text](path/to/image.jpg){: .hero-image }

Caption text here.
{: .figure-caption }
```

### Video with caption

Videos need the shared wrapper — don't just drop a bare `<video>` tag, it
won't center or round its corners correctly on its own.

```markdown
<div class="video-wrap" markdown="1">

<video controls>
  <source src="path/to/video.mp4" type="video/mp4">
  Your browser does not support the video tag.
</video>

Caption text here.
{: .video-caption }

</div>
```

### Download cards (CAD/manufacturing file bundles)

```markdown
<div class="download-cards" markdown>

<div class="download-card" style="--accent:#4A90D9;" markdown>
<span class="card-icon">:fontawesome-solid-draw-polygon:</span>

**Bundle Name**

Short description of what's in it.

[Download](path/to/file.zip){: .md-button :download}

</div>

</div>
```

### Scrolling render strip

```markdown
<div class="render-scroll" markdown>

![Render 1](path.png){: data-gallery="unique-name" }
![Render 2](path.png){: data-gallery="unique-name" }

</div>
```

### Notes/warnings

```markdown
!!! note "Optional Title"
    Body text, indented four spaces.

!!! warning "Optional Title"
    Body text, indented four spaces.
```

### The one attr_list rule that trips people up

The `{: .class-name }` attribute line must sit **directly under** the text
it applies to, on its **own line**, with **no blank line** between them.
Putting it on the same line as the text, or adding a blank line before it,
means it won't apply and will just show up as literal text on the page.

```markdown
Correct:
Some text.
{: .some-class }

Wrong (renders literally, class doesn't apply):
Some text.{: .some-class }

Also wrong (blank line breaks it):
Some text.

{: .some-class }
```

---

## 8. Troubleshooting

**CAD download bundles (.zip/.step/.3mf) look broken/tiny after cloning.**
Git LFS wasn't installed before you cloned. Install it (Section 2), then
run `git lfs pull` from inside the project folder to fetch the real files.

**`mkdocs: command not found`**
The virtual environment isn't active. Run
`source .venv/bin/activate` (Mac/Linux/Git Bash) or
`.venv\Scripts\activate` (Windows Command Prompt) from inside the project
folder, then try again. You'll know it worked if your terminal prompt
starts showing `(.venv)`.

**A caption or styled element shows up as plain text with `{: .some-class }`
literally visible on the page.**
See "The one attr_list rule that trips people up" above — almost always a
missing/extra blank line around the attribute tag.

**`git push` is rejected / says the branch is behind.**
Someone else pushed changes since you last pulled. Run `git pull` first
(GitHub Desktop: **Fetch origin** → **Pull origin**), resolve any conflicts
it flags, then push again.

**The live site hasn't updated after I pushed.**
Check the **Actions** tab on the repo's GitHub page — the deploy takes a
minute or two, and if it failed the tab will show a red ✕ with logs
explaining why (usually a broken Markdown/YAML syntax error). A hard
refresh (Ctrl+Shift+R / Cmd+Shift+R) also rules out browser caching.

---

## 9. Glossary

Plain-language definitions for the jargon used throughout this guide.

| Term | Meaning |
|---|---|
| **Repo (repository)** | The project's folder, tracked by Git, hosted on GitHub |
| **Clone** | Downloading a full copy of the repo onto your computer |
| **Commit** | A saved snapshot of changes, with a short description attached |
| **Push** | Uploading your local commits to GitHub |
| **Pull** | Downloading commits others have pushed since you last checked |
| **Branch** | An independent line of edits (this project mainly just uses `main`) |
| **Markdown (.md)** | The plain-text format used to write every page — see [this cheat sheet](https://www.markdownguide.org/cheat-sheet/) for the basics if you're new to it |
| **YAML (.yml)** | The format `mkdocs.yml` is written in — spacing/indentation matters, so edit carefully |
| **MkDocs** | The tool that turns the Markdown files into the actual website |
| **GitHub Actions** | The automation that rebuilds and republishes the site every time you push |
| **GitHub Pages** | The free hosting GitHub provides for the built site |

</div>

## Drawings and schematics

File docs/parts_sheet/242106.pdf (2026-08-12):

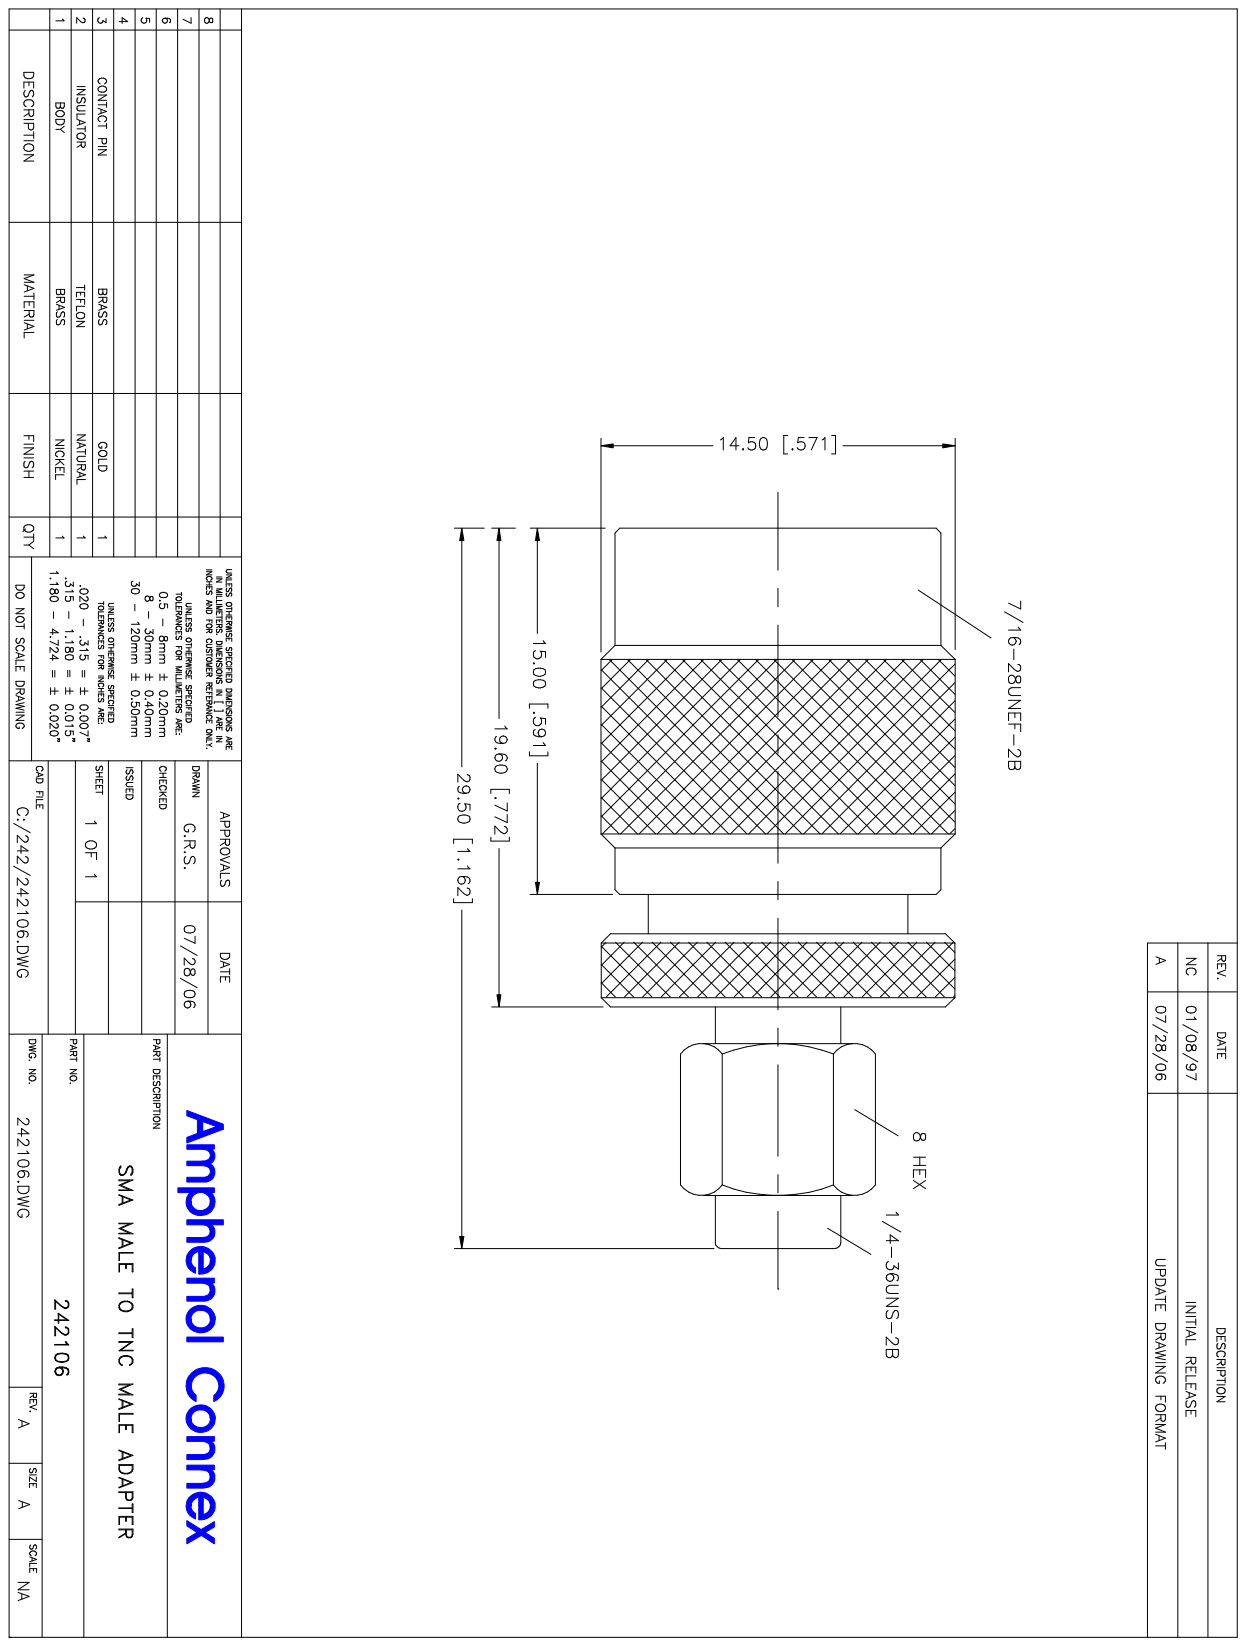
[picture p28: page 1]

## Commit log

2026-07-21 Initial repository structure and project images
    Added initial folder structure, hardware images, and documentation framework for RIFTS hardware archive.
2026-07-21 Added images of enclosure accessories as well as formatting to the accessory window.
2026-07-21 Add cooling air duct CAD and manufacturing files
    [RIFTS_Cooling_Air_Duct_Type_A.SLDPRT, RIFTS_Cooling_Air_Duct_Type_A.STEP, RIFTS_Cooling_Air_Duct_Type_A.STL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]
2026-07-22 a ton of stuff
    [Corner_Pad_Insert.SLDPRT, Corner_Pad_Insert.STEP, Corner_Pad_Insert.STL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]
2026-08-04 Add case-insensitive LFS tracking for CAD models
    [50mm ID x 3.5mm CS O Ring.SLDPRT, AMD_Xilinx_RFSoC_4x2_Board.SLDPRT, AMD_Xilinx_RFSoC_4x2_Board_Simplified.SLDPRT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]
2026-08-06 Stop tracking build output
    [50mm ID x 3.5mm CS O Ring.SLDPRT, AMD_Xilinx_RFSoC_4x2_Board.SLDPRT, AMD_Xilinx_RFSoC_4x2_Board_Simplified.SLDPRT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]
2026-08-07 cleaning up
    [5in_PVC.SLDPRT, 5in_PVC.STEP, AMD_Xilinx_RFSoC_4x2_Board.SLDPRT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]
2026-08-07 deleted unecessary files
    [Assem2.SLDASM, Corner_Pad_Insert.SLDPRT, Corner_Pad_Insert.STEP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]
2026-08-10 Added pvc pipe support manufacturing files
    [RIFTS_WaterImmersion_FixtureSupport.STL, RIFTS_WaterImmersion_FixtureSupport_PrintPackage.3mf]
